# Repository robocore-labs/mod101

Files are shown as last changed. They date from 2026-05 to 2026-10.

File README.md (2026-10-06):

# mod101



**An open-source, universal robot arm platform.**

Robot arms are cool,  but no two people want the same one. Bolt a dremel to it
for light machining and you need a short reach and real payload. Put a camera
on it for inspection work and you want the exact opposite: long reach, almost
nothing to carry. Yet nearly every platform out there, commercial and open
source alike, picks one point on that tradeoff and casts it in stone.

mod101 doesn't. It's a 5-DOF arm designed as a *base* you build on: size it for
your reach envelope, snap in whichever tool the job needs (gripper, vacuum,
camera, dispenser…), and drive it with whatever stack you like — ROS 2, MoveIt,
direct serial, LeRobot.

## Features

- 🔧 **Resize it** — shoulder and elbow extrusions are parametric; tweak from the web configurator with live preview.
- 🧰 **Hot-swap tools** — every end-effector is its own ROS 2 package. Ships with a parallel-jaw gripper, a PincOpen pincer, and a blank end-cap.
- 🤖 **Embeddable** — the whole arm is a prefix-parameterized xacro macro; mount one (or two, or four) on any robot with a one-line `<xacro:mod101_arm .../>` call. No name collisions, no forking.
- 💪 **Lifts up to 3kg and more** with two ST3120 servos — same brackets, just bigger shoulder servos.
- 📏 **Reaches up to 80cm and more** with long extrusions and beefy servos.
- 🌐 **Web configurator** — `python3 configurator/server.py` and you're can use the interactive configurator to tweak the arm to your liking. 
- 🎯 **Guided calibration** — move each joint by hand and the browser learns its limits, flags a binding joint, and writes the config for both ROS 2 and LeRobot.
- 🧠 **MoveIt 2 ready** — motion planning, collision-aware IK and trajectory execution in one launch, with a solver that actually suits a 5-DOF arm. The SRDF is parametric too, so it follows your build.
- 🛠️ **Real structure, not a printed shell** — 2020 aluminum extrusions + PETG-CF brackets at the joints.
- 🌍 **Open** — MIT licensed, no proprietary parts, BOM under $135 entry-level.

## Configurator

**Work out what arm you actually need — before you cut any aluminum or buy a
single servo.**

```bash
source /opt/ros/jazzy/setup.bash   # the 3D preview needs this
python3 configurator/server.py     # then open http://localhost:8001/
```

Drag the sliders and the arm rebuilds itself in front of you. Make the forearm
longer and watch the reach grow — and the payload drop. Swap the shoulder to a
beefier servo and watch it climb back. Every change answers the question that
actually matters when you're about to spend money: *will this arm do my job?*

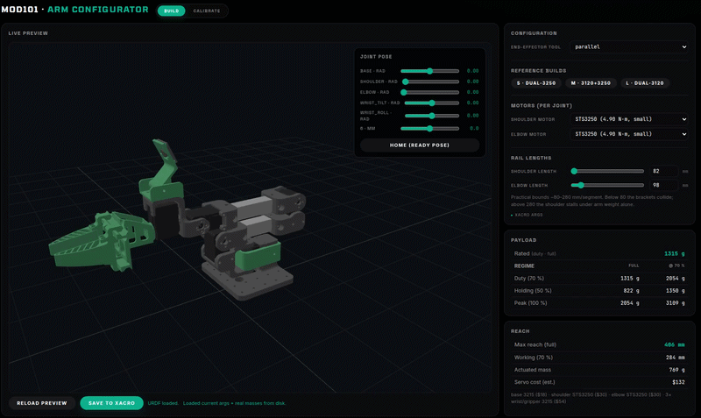
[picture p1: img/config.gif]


Four things to decide:

- **How long** — shoulder and forearm rail lengths, i.e. how far it reaches.
- **How strong** — which servo at the shoulder and the elbow.
- **What's on the end** — gripper, pincer, single jaw, or nothing.
- **Or just start from a preset** — **S**, **M** and **L** are known-good
  builds if you'd rather not start from scratch.

And it tells you, live, what you'd get:

- **What it can lift**, at full stretch and pulled in — plus *which joint*
  gives out first, so you know what to upgrade.
- **How far it reaches** and **what it weighs**, from the real printed part
  masses.
- **What the servos cost** — usually the number that decides the build.

Grab the joint sliders to pose it and check the arm actually reaches into your
workspace. When it looks right, hit **Save**: that configuration *is* your
robot from then on, in sim and on the bench. Nothing to copy by hand.

Endpoint reference and internals: [`docs/configurator.md`](docs/configurator.md).

## Calibration

**You've built the arm. Now teach it where its joints actually stop.**

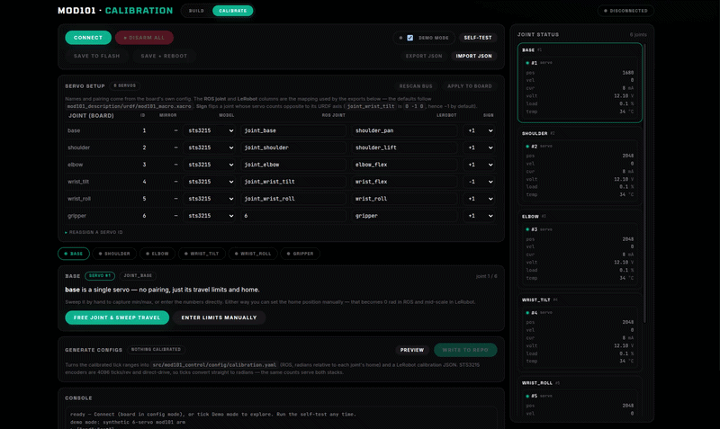
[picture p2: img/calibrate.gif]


Straight off the bench a servo has no idea which way it's mounted or how far
the bracket lets it swing. Calibration is what turns six motors into a robot
that matches the URDF — and it's the step where you find out whether you
assembled it correctly.

Plug the arm and go joint by joint. Each one:

- **Goes limp so you can move it by hand.** Swing it stop to stop and the
  wizard watches where it actually travels — no guessing at limits, no
  numbers to look up. It backs off slightly from each hard stop so the servo
  never grinds.
- **Gets a verdict — clean, binding, or fault.** This is the part worth having.
  A joint that catches, or an encoder that slipped during assembly, shows up
  here as a bad sweep instead of as a crash later with a gripper full of your
  workpiece.
- **Powers up carefully.** It re-arms slowly and checks how hard the servo is
  pulling before letting it move. Too much current and it disarms itself,
  which usually means something is fighting the joint.
- **Gets a drive test**, so you can watch it track across the range you just
  set before trusting it.

The arm is left powered down at every exit, including if you close the tab or
yank the cable.

When you're done, **Write to repo** saves the results for both ROS 2 and
LeRobot, so the arm you calibrated is the arm your code drives.

No hardware yet? Tick **Demo mode** and the whole flow runs against a
simulated arm — a good way to see what you're in for before you order servos.

Talks to the servos directly over the USB-TTL adapter (`pip install st3215`) —
no intermediate firmware, and nothing is written to servo EEPROM. Any browser.
Full details, including the joint/servo mapping and the tick math:
[`docs/calibration.md`](docs/calibration.md).

## Tools

Every end-effector is a standalone ROS 2 package (`mod101_tool_<name>`) carrying its own URDF, controllers, gazebo extensions, and launch fragment. Pick one at launch time with `tool:=<name>`.

| Tool | Preview | Description | 
|---|---|---|
| `parallel` |  | Parallel-jaw gripper, single prismatic joint with a mimic'd right jaw. |
| `pincopen` |  | [PincOpen](https://github.com/CNURobotics/pinc_open_driver) pincer gripper (Pollen Robotics). Single revolute drive + 4-bar linkage. | 
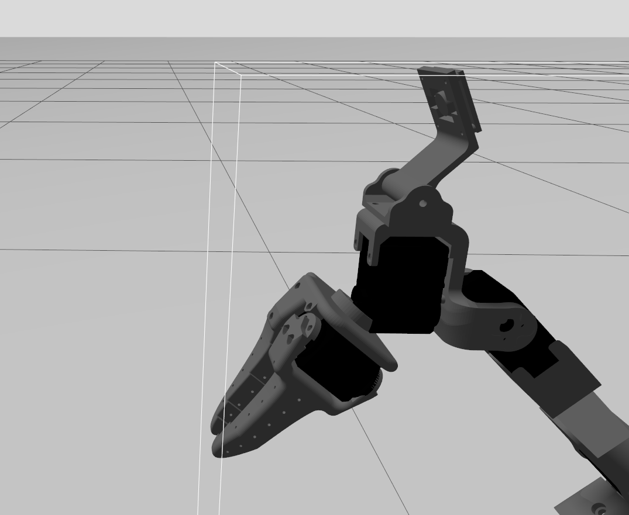
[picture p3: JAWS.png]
| `jaws` |  | SO-101 single-jaw gripper — moving jaw rotates against the fixed wrist-roll body. Cheapest tool, just one extra servo. **Default.** | 
| `none` |  | Blank end-cap. No actuators — useful as a baseline or a template for a new tool. |

Adding your own is a one-package job (URDF + ros2_control + SRDF + launch). See [`docs/tool-convention.md`](docs/tool-convention.md) for the coordinate convention every tool follows, and [`docs/ros-architecture.md`](docs/ros-architecture.md#adding-a-new-tool) for the package contract.

## Getting started

You'll need ROS 2 Jazzy on Ubuntu 24.04. Everything else (Gazebo Harmonic, `ros2_control`, `gz_ros2_control`) installs via apt.

```bash
# 1. Clone next to (or into) a colcon workspace
git clone https://github.com/<you>/mod101.git ~/robots/mod101
cd ~/robots/mod101

# 2. Build the arm + the tools you want
colcon build --packages-select \
  mod101_description mod101_control mod101_gazebo mod101_moveit_config \
  mod101_tool_parallel mod101_tool_pincopen mod101_tool_jaws mod101_tool_none
source install/setup.bash

# 3. Launch sim — pick a tool with the `tool:=` arg
ros2 launch mod101_gazebo gazebo.launch.py tool:=parallel
```

### Or in containers

Two containers, no ROS install needed: the simulation (this repo, built into
one image) and the robocore agent (pulled, not built here).

```bash
docker compose -f docker/compose.yaml up --build
```

That gives you the bench in Gazebo plus the robocore API on
`ws://localhost:10101`. The agent needs no configuration beyond
`profiles/mod101_harness.yaml`, which compose mounts for you.

Want motion planning? `sudo apt install ros-jazzy-moveit ros-jazzy-pick-ik`, then:

```bash
ros2 launch mod101_moveit_config demo.launch.py   # Gazebo + MoveIt + RViz
```

Plan and execute from the RViz MotionPlanning panel. Full walkthrough, including
a scripted first motion:
[`docs/moveit-getting-started.md`](docs/moveit-getting-started.md).

One thing worth knowing up front: mod101 is a 5-DOF arm, so it plans to
**positions**, not full 6-DOF poses — the guide explains why and what that means
for grasps.

Try the configurator while sim is running:

```bash
python3 configurator/server.py  # http://localhost:8001/
```

## Running on real hardware

The bench in containers, against the actual arm. Same shape as the sim stack:
one image built from this repo, one pulled for the agent.

**Calibrate first.** The arm has no configuration stored on it, so without a
calibration every joint angle is offset by wherever its servo horn happened to
be splined on. See [`docs/calibration.md`](docs/calibration.md); it takes a few
minutes per joint and only has to be done once per arm.

```bash
docker compose -f docker/hardware.compose.yaml up --build
```

That is the whole thing. The build clones the driver packages itself
(`src/hardware/hardware.repos`), and the servo bus is found at
`/dev/mod101-servo`. `docker/hardware.env.example` covers the cases that differ
from this bench; none of it is required.

**Install the udev rules once**, so the bus and the camera come up under names
that survive a replug:

```bash
sudo cp docker/udev/*.rules /etc/udev/rules.d/
sudo udevadm control --reload-rules && sudo udevadm trigger
ls -l /dev/mod101-servo          # -> ../ttyACMn
```

The servo rule matches the RS-485 adapter by **serial number**, so edit it if
you swap cables (the file says how). Without it, set `MOD101_BUS=/dev/ttyACMn`
in `.env` and re-check it after every replug. The RealSense rule grants raw USB
access to a non-root container; **replug the camera** after installing it,
because udev does not re-apply modes to a device that is already open.

Working on the drivers? The image contains what is on `main`, not what is
checked out locally — push first, then bust the cached clone:

```bash
docker compose -f docker/hardware.compose.yaml build \
  --build-arg DRIVERS_CACHEBUST=$(date +%s)
```

That gives you three things:

| | |
|---|---|
| the robot | `ros2_control` on the real servo bus, plus per-motor telemetry on `/motor_telemetry/<joint>/*` |
| the head camera | the D435 on `/harness/depth_camera/*` — the same topic names the sim publishes |
| <http://localhost:8888> | ROSBoard — the graph in a browser, **and joint sliders that move the arm** |
| `ws://localhost:10101` | the robocore agent |

Stop it with `docker compose -f docker/hardware.compose.yaml down`. Use that
rather than Ctrl-C'ing a host launch: killing a launch by hand takes the
launcher and leaves its `robot_state_publisher` running, which then publishes
`/robot_description` and TF into the *next* run's graph.

### Before the first run

**Bringing the stack up energises the arm.** Every servo is armed and told to
hold its present position — no jump, but live and drawing current. Two things
follow from that:

- **Put the arm somewhere it can hold, and near its calibrated home.** A joint
  resting outside its calibrated travel gets its first command clamped back
  into range, which turns "hold still" into a move of however far outside it
  was. The driver refuses to start when that distance is more than a few
  degrees, rather than making the move.
- **There is no e-stop in this stack.** `brake_method: torque_disable` drops
  torque when a group is commanded to stop; nothing here cuts power.

A dry run first is free, and touches nothing:

```bash
docker compose -f docker/hardware.compose.yaml run --rm --no-deps hardware \
  ros2 launch mod101_hw_bringup bringup.launch.py \
  hardware:=mock bus:=false cameras:=false
```

`bus:=false` is the real dry run — the servo driver does not start, so nothing
is energised. `hardware:=mock` alone is not: it only swaps the `ros2_control`
plugin, and the driver is a separate node that arms motors regardless.

### When it doesn't come up

| what it says | what it is |
|---|---|
| `N of M motors did not answer` | motor power. The logic side is USB-fed, so the port opens and the chain stays silent — it looks like a working driver with a dead robot |
| `is at N, outside its calibrated travel` | move that joint back by hand (torque is off) and start again, or recalibrate if the range is wrong |
| `could not open port` | no `/dev/mod101-servo` (udev rules not installed?), or the container user is not in the host's `dialout` group (`DIALOUT_GID` in `.env`) |
| `NO CALIBRATION at ...` | it will run, uncalibrated, and every angle will be wrong. Run the configurator |
| camera: `no device detected` while `lsusb` shows it | the RealSense udev rule is missing or the camera was not replugged after installing it. The `cameras` service runs as your UID and librealsense needs raw USB **write** access |

Prefer `/dev/mod101-servo` to `/dev/ttyACMn`. ACM numbering is assignment
order, not identity, and it moves whenever anything re-enumerates — it shifted
once mid-session on this bench. Getting it wrong does not report a wrong port:
the port opens, nothing answers, and it reads as unpowered motors.

The cameras are their own service, so they can be restarted, stopped or
followed without touching the arm:

```bash
docker compose -f docker/hardware.compose.yaml logs -f cameras
docker compose -f docker/hardware.compose.yaml restart cameras
```

Full detail, including the arguments and what each config file owns:
[`src/hardware/mod101_hw_bringup/README.md`](src/hardware/mod101_hw_bringup/README.md).

## Embedding in another robot

The arm is defined as the `mod101_arm` xacro macro
(`mod101_description/urdf/mod101_macro.xacro`); the standalone `mod101.xacro`
is just a thin wrapper that instantiates it once with an empty prefix. Any
robot can include the macro file and bolt on as many arms as it likes:

```xml
<xacro:include filename="$(find mod101_description)/urdf/mod101_macro.xacro"/>

<xacro:mod101_arm prefix="left_arm_"  parent="left_arm_bracket"
                  xyz="0 0.06 0.024" rpy="0 0 0"
                  tool="jaws" use_sim="true"/>
<xacro:mod101_arm prefix="right_arm_" parent="right_arm_bracket"
                  xyz="0 -0.06 0.024" rpy="0 0 0"
                  tool="jaws" use_sim="true"/>
```

| Param | Default | Meaning |
|---|---|---|
| `prefix` | `''` | Prepended to **every** link/joint name. Joints become e.g. `left_arm_1 … left_arm_6`; the wrist camera topic becomes `<prefix>wrist_camera/image_raw`. |
| `parent` | `''` | Link to bolt the arm base onto via a fixed `<prefix>base_mount` joint. Empty = no mount joint (the caller anchors `<prefix>base_link` itself). |
| `xyz`, `rpy` | `0 0 0` | Mount joint origin in the parent frame. The base plate is 80×100 mm, centred on `base_link`. |
| `tool` | `jaws` | End-effector package (`mod101_tool_<tool>`). |
| `use_sim` | `true` | Emit the gz_ros2_control hardware blocks + gazebo extensions. |

The macro emits a complete, independently named `<ros2_control>` system per
instance (plus one per tool), so a single `gz_ros2_control` plugin /
controller_manager handles them all — the integrator just declares the
plugin once and supplies controller YAML with the prefixed joint names. The
reference integration is the base101 dual-arm workspace (two arms on a
mobile base's lift tower).

## Optional: `mod101_harness`

`mod101_harness` is an **optional overlay** package (built with the rest,
depended on by nothing): the arm on a bench test harness — 2020 extrusion base,
camera tower with an actuated pan/tilt head and a RealSense depth camera. It
reuses mod101's arm description and controller set unchanged and adds only the
harness structure, the two `hn_pan_joint` / `hn_tilt_joint` joints (one extra
controller, `config/pan_tilt_controllers.yaml`) and the depth camera. Two
launch files:

```bash
# whole robot in Gazebo: arm + pan/tilt + RealSense depth (RGB/depth/points on
# /harness/depth_camera/*) + the arm's wrist camera, all bridged
ros2 launch mod101_harness sim.launch.py

# prepared-for-hardware skeleton: robot_state_publisher + controller_manager on
# a mock_components placeholder, same controllers spawned. Runs as fake hardware
# as-is; swap the plugin in urdf/mod101_harness_arm.xacro to go live.
ros2 launch mod101_harness hardware.launch.py
```

Same `tool:=` / rail-length / mount args as `mod101_gazebo`. No MoveIt launch —
point `mod101_moveit_config`'s `move_group` at this package's xacro/srdf if you
want planning. The arm mount pose was solved by rigidly aligning the export's
stand-in base against `base_link.stl`; `urdf/harness_body.xacro` is the ported
geometry, `export/` the untouched baseline for the next re-export.

### Deeper docs

**Get it moving**

- **[docs/moveit-getting-started.md](docs/moveit-getting-started.md)** — the walkthrough: install to first executed motion, ~15 minutes, no hardware
- **[docs/moveit.md](docs/moveit.md)** — the MoveIt reference: the 5-DOF IK story, what to regenerate when you change the build, controller wiring, and what every planning failure means

**Change it**

- **[docs/configurator.md](docs/configurator.md)** — sizing the arm: endpoint reference, how the live xacro edit works, what a Save does and doesn't do
- **[docs/tool-convention.md](docs/tool-convention.md)** — coordinate convention for tool URDFs (mount joint identity, `+X` outward, `+Z` up, bolt pattern at origin)
- **[docs/calibration.md](docs/calibration.md)** — hardware bring-up: the per-joint sweep wizard, and the ROS + LeRobot config it generates

**Understand it**

- **[docs/ros-architecture.md](docs/ros-architecture.md)** — package layout, the tool contract, controllers, the joint table, real-hardware wiring, known gotchas
- **[docs/performance-notes.md](docs/performance-notes.md)** — measured performance, where bringup time really goes, and the middleware traps that masquerade as code bugs

**History** — kept for reasoning and measurements, not current documentation

- **[docs/worklogs/moveit.md](docs/worklogs/moveit.md)** — the original MoveIt handover note and the collision-matrix measurements behind today's design

## BOM

### Base Config (~$134)

| Part | Qty | Unit Price | Subtotal |
|---|---|---|---|
| [STS3215 servo (12V, 30 kg·cm)](https://www.alibaba.com/product-detail/Low-Cost-Feetech-STS3215-Servo-7_1601611431055.html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) | 6 | $16.50 | $99.00 |
| 2020 aluminum extrusion (cut to length) | ~0.6m | $5.00/m | $3.00 |
| M5 T-nuts | ~20 | — | $3.00 |
| M5×8 bolts | ~20 | — | $2.00 |
| PLA-CF filament (~150g) | — | — | $8.00 |

| Misc hardware (bolts, nuts, wires) | — | — | $10.00 |
| **Total** | | | **~$134** |

If you want to upgrade the motors for more payload, here are the options: [**STS3250 at 50kg*cm**](https://www.alibaba.com/product-detail/12V-50kg-STS3250-Coreless-Motor-Magnetic_1601756525163.html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) or [**the 120kg*cm beast STS3120**](https://www.alibaba.com/product-detail/Feetech-STS3120M-12V-120kg-High-Performance_1601816393864.html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). Brackets are available for both, check the configurator for more details. 

## Related Projects

- **[Axon](https://github.com/robocore-labs/link101-hw)** — RP2350-based multi-protocol bridge (CAN FD / RS485 / Dynamixel / Feetech)
- **[Forge](https://github.com/cristidragomir97/forge)** — ROS 2 deployment orchestration

## Acknowledgments

- Derived from the [SO-101](https://github.com/TheRobotStudio/SO-ARM100) by The Robot Studio.
- Parallel-jaw gripper is the [PathOn 6DOF symmetric gripper](https://github.com/PathOn-AI/pathon_opensource).
- PincOpen pincer tool vendors URDF + meshes from [CNURobotics/pinc_open_driver](https://github.com/CNURobotics/pinc_open_driver) (original gripper design by Pollen Robotics).

## License
MIT

## 6DOF / 7DOF arm variants

Choose **Arm variant** in the configurator. The selector updates the preview,
servo cost and payload estimate; **Save to xacro** persists it for ROS launches.
Both variants use the same end-effector packages and `wrist_flange` interface.
The project's names count the tool actuator: 6DOF has five arm axes; 7DOF adds
`joint_wrist_yaw` before wrist pitch/roll, giving six arm axes. With `tool:=none`
there is no tool actuator.

```bash
source /opt/ros/jazzy/setup.bash
colcon build --symlink-install
source install/setup.bash
ros2 launch mod101_moveit_config mock.launch.py arm_dof:=7 tool:=pincopen
# Other description, Gazebo, harness and hardware launches accept arm_dof too.
```

For an imported arm, pass `arm_dof="7"` to `mod101_arm` and the matching
`mod101_arm_srdf`. The default remains 6, preserving existing consumers.
Include `mod101_config.xacro` and pass `arm_dof="$(arg arm_dof)"` to follow the
saved configuration. Each instance can select its own variant and tool.

The added wrist geometry and shaft pivots come from `mod101_7DOF.step`; the STEP
has 100 mm shoulder and 110 mm elbow rails. Rail lengths remain configurable.
The added yaw servo is an STS3215, **56 g**, with provisional **±90°** limits.
Default bus ID is **9**, preserving tool ID 6 and head IDs 7/8. Calibrate the new
joint and write a matching servo map before hardware use; an old map with the
wrong joint set is rejected by hardware bring-up.

Payload estimates preserve the existing 6DOF/jaws reference calculation,
including its joint-capacity and lumped-weight assumptions. The user confirmed
the 140/140 mm jaws configuration lifts over 700 g on the bench; its previous
calculator result remains unchanged (911 g duty/full with STS3250 selections).
The 7DOF model applies differences calculated from both URDFs at identical rail
lengths: the new actuator/printed masses, COMs and changed load-point leverage.
Other tools use the same correction relative to jaws. This extrapolation needs
its own bench validation; it does not establish a rated load. Existing estimated arm plastics and the new wrist use **PETG,
1.27 g/cm³, 15% infill, 1.6 mm shell**. The separate tool packages retain their
own authored mass estimates. New wrist mass/inertia provenance is recorded in
`src/mod101_description/config/7dof_measurements.json`; print COM/inertia uses
uniform effective density. Slicer or measured weights can improve these estimates.

The calculator evaluates a horizontal extended pose. Tool reach uses its distal
visual extent as a provisional load point; 70% reach scales the levers rather
than solving a new pose. Stall-torque fractions are estimates, not rated payloads.
After saving lengths/mounts, rebuild collision matrices from the configurator;
its regeneration samples both arm variants independently for every tool.

```bash
python3 -m pytest tests/test_arm_variants.py
python3 src/mod101_moveit_config/test/moveit_smoke.py --arm-dof 7
# The second command needs the matching mock launch running.
```

The configurator's **Wrist camera** checkbox controls the camera, both printed
mounts, sensor/frame definitions and MoveIt collision references on either arm
variant. **Save to xacro** persists it. ROS launches also accept
`wrist_camera:=false`; imported URDF and SRDF macros accept `wrist_camera="false"`.
Hardware bring-up skips the wrist-camera driver when the option is disabled.

The parallel tool now includes a black STS3215 servo visual in its existing
body link. The mesh is reused from the repository's CAD extraction; the tool's
existing combined body mass/inertia remains unchanged.

## Camera mount tool and package-defined options

Select **Camera mount** in the configurator to choose between **Luxonis (61 g)**
and **RealSense (72 g)**, with an optional **GoPro (153 g)** above it. The PETG
holder is approximately **46.2 g** at 15% infill with the 1.6 mm shell assumption.
Both 6DOF and 7DOF variants support the same options and include their mass in
the payload estimate. The existing jaws reference calculation is preserved.

`mod101_tool_camera` includes the STEP-derived meshes, authored inertials and
`camera_tool_gopro_optical_frame`. It is passive and requires no tool actuator.
See [camera package notes](src/mod101_tool_camera/README.md) and the
[tool options API](docs/tool-options.md) for the YAML schema and ROS arguments.

### NormaCore PGGripper

Select **PGGripper** in the configurator or pass `tool:=pggripper` to the existing launch commands. The [end-effector package](src/mod101_tool_pggripper/README.md) includes its ST3215 servo, rack-and-pinion jaw motion, ROS controllers and collision matrices for both arm variants. Estimated mass is 154g using PETG at 15% infill; rated aperture is 54mm.

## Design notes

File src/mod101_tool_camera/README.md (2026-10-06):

# Camera mount end effector

Passive wrist-flange tool extracted from `camera_tool.step`. The mount origin
is the rear face at the centre of the +/-7 mm bolt pattern. +X points out of
the lenses; +Z places the GoPro above the selected depth camera.

In the configurator select **Camera mount**, choose **Luxonis** or **RealSense**,
and optionally enable **Top GoPro**. Save to persist the configuration.
The primary cameras are mutually exclusive in the URDF, not merely hidden
in the preview. The GoPro body, mass, and optical frame are all removed when off.

```bash
ros2 launch mod101_moveit_config mock.launch.py \
  tool:=camera camera_sensor:=realsense camera_gopro:=true arm_dof:=7
```

Imported `mod101_arm` macros accept `camera_sensor` and `camera_gopro` per
instance. The paired `mod101_arm_srdf` accepts the same GoPro flag. No extra
joint, controller, or servo is created; camera drivers are separate from this
mechanical description package.

| Component | Mass |
|---|---:|
| PETG holder (15% infill, 1.6 mm shell, 1.27 g/cm³) | 46.2 g estimated |
| Luxonis | 61 g (user supplied) |
| RealSense | 72 g (user supplied) |
| GoPro | 153 g (user supplied) |

The holder includes its GoPro mounting fork even with the camera absent.
COM/inertia assume uniform effective density in each CAD component; camera
masses use the supplied weights. Source hash, geometry measurements, tensors,
and the CAD-to-tool transform are recorded in `config/measurements.json`.
`tools/export_camera_tool.py` reproduces the meshes and mass measurements;
`urdf/tool.urdf.xacro` remains the authored robot description.

`<prefix>camera_tool_gopro_optical_frame` follows REP-103: +Z forward, +X image
right, +Y down. Its origin is the front lens-window centre measured from CAD,
at `(35.1851, 21.5930, 66)` mm in tool coordinates. It is a mechanical reference;
use camera calibration for imaging intrinsics and precise optical extrinsics.
The GoPro stays fixed at its exported pose.

Visual meshes preserve the vendor STEP surfaces, including imported seams;
collision shapes are conservative boxes. The primary box is the union of both
camera envelopes so the sampled collision matrix is valid for either choice.
Collision pairs involving the optional GoPro are omitted when it is disabled.

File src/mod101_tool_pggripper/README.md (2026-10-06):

# PGGripper for mod101

Adapted from [NormaCore Parallel Jaw Gripper](https://github.com/norma-core/norma-core/tree/main/hardware/pgripper), licensed Apache-2.0. Original license and STEP are included. Meshes and kinematic description are adapted for mod101; upstream optional webcam/mount are omitted. Keep mod101 wrist camera enabled if required.

Select **PGGripper** in the configurator, or pass `tool:=pggripper` to the normal ROS launch commands. Supports both 6DOF and 7DOF, prefixed multi-arm macros, gripper position and trajectory controllers.

Joint `6` is the motor rotation in radians, zero closed and approximately 2.271 radians fully open. Two passive prismatic mimic joints convert rotation through the CAD rack pitch (4.15mm, 18 teeth); 27mm travel per jaw / 54mm aperture. Imported STEP is at a measured 50mm aperture. Servo mounting orientation and phase are retained; calibrate motor zero/sign on hardware before commanding it.

Mass estimate: PETG 15% infill with 1.6mm shell, 56g ST3215-family actuator, steel hardware at 7850kg/m³. Total approximately 154g, with CAD-derived COM and inertia. These are estimates, not weighed parts; upstream filament requirement includes print supports and differs. Cameras are not included in this package mass.

`config/measurements.json` records datums, source hash and computed mass properties. `tools/export_pggripper.py` exports meshes/measurements; authored xacro owns the robot description. Imported CAD includes faces without mesh triangulation; collision checking uses the available triangulated geometry.

The hardware interface follows the existing gripper bridge/mock/Gazebo selection. Motor torque and speed limits are provisional (1.9Nm, 2rad/s). Passive sliders have no command interfaces.

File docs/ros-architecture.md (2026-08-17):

# ROS 2 architecture

mod101 follows the standard ROS 2 description / control / gazebo layout, with a **modular tool layer**: every end-effector lives in its own `mod101_tool_<name>` package that ships everything it needs (URDF, ros2_control hardware block, gazebo extensions, controllers YAML, launch).

Target distro: **Jazzy** (Ubuntu 24.04, Python 3.12, Gazebo Harmonic).

## Packages

| Package | Build type | Purpose |
|---|---|---|
| `mod101_description` | `ament_cmake` | Arm URDF/xacro, meshes, RViz config, `display.launch.py`. The arm itself is the **`mod101_arm` macro** in `mod101_macro.xacro` (prefix-parameterized so multiple instances can coexist in one robot); `mod101.xacro` is the thin standalone wrapper; `mod101.ros2control` / `mod101.gazebo` hold the matching per-instance macros. Terminates at the `wrist_flange` link — the contract point for tools. |
| `mod101_control` | `ament_cmake` | Arm controller YAML (`controllers.sim.yaml`), real-hardware overlay (`mod101.hardware.xacro` — placeholder plugin) |
| `mod101_gazebo` | `ament_cmake` | World (`empty.sdf`, bullet-featherstone physics), bridge config, `gazebo.launch.py` (accepts `tool:=<name>`) |
| `mod101_tool_parallel` | `ament_cmake` | Parallel-jaw gripper |
| `mod101_tool_pincopen` | `ament_cmake` | PincOpen pincer gripper (vendored from [CNURobotics/pinc_open_driver](https://github.com/CNURobotics/pinc_open_driver)) |
| `mod101_tool_jaws` | `ament_cmake` | SO-101 single-jaw gripper (URDF + meshes adapted from the SO-101 lineage) |
| `mod101_tool_none` | `ament_cmake` | Empty end-cap. No actuators, no controllers — useful as a baseline / template |
| `mod101_moveit_config` | `ament_cmake` | MoveIt 2: parametric SRDF (`srdf/mod101.srdf.xacro`), 5-DOF-aware IK, generated collision matrices, `demo`/`mock`/`move_group` launches. See [moveit.md](moveit.md) |

## The `mod101_arm` macro

Everything that *is* the arm — links, joints, ros2_control hardware block,
gazebo extensions, the selected tool — is emitted by one macro:

```xml
<xacro:include filename="$(find mod101_description)/urdf/mod101_macro.xacro"/>
<xacro:mod101_arm prefix="" parent="world" xyz="0 0 0" rpy="0 0 0"
                  tool="jaws" use_sim="true"/>
```

`prefix` is prepended to every link/joint/system name and the wrist-camera
topic, so multiple instances coexist cleanly (`left_arm_1…6`, etc.).
`parent` adds a fixed `<prefix>base_mount` joint to the given link (empty =
no mount joint). `use_sim` gates the gz_ros2_control system blocks + gazebo
tags per instance.

Two things deliberately stay **outside** the macro, in the standalone
wrapper `mod101.xacro`: the `world` anchor link and the gz_ros2_control
**plugin** declaration (one per robot — an integrator with its own plugin
block, like base101, must not inherit a second one). `mod101.xacro` keeps
the original `use_sim` / `tool` args, so single-arm bringup is unchanged.

## Tool layer

The macro's `tool` param (arg `tool` on the standalone wrapper, default
`jaws`) selects which `mod101_tool_<tool>` macro to invoke; the tool's links
are fixed-jointed to `<prefix>wrist_flange`. The Gazebo plugin block in
`mod101.xacro` loads `mod101_control`'s arm YAML **plus** the active tool's
YAML (multiple `<parameters>` files merge into the single
`controller_manager` namespace); the launch file `IncludeLaunchDescription`s
the tool's `launch/tool.launch.py` to spawn whatever controllers / bridges /
drivers the tool needs.

### Adding a new tool

Create `mod101_tool_<name>/` with:

```
urdf/tool.urdf.xacro        # macro mod101_tool_<name>(prefix, use_sim): links + fixed joint to ${prefix}wrist_flange
urdf/tool.ros2control       # optional: macro mod101_tool_<name>_ros2control(prefix, use_sim)
urdf/tool.gazebo            # optional: macro mod101_tool_<name>_gazebo(prefix)
srdf/tool.srdf.xacro        # optional: macro mod101_tool_<name>_srdf(prefix) — MoveIt group + end effector
config/controllers.yaml     # optional
config/moveit_controllers.yaml  # optional: this tool's FollowJointTrajectory entry for MoveIt
launch/tool.launch.py       # spawners, image bridges, drivers, ...
```

`launch/tool.launch.py` must declare a `spawn_controllers` argument (even if it
ignores it, as `mod101_tool_none` does) — `mod101_gazebo` passes it to every
tool launch, and an include handed an argument it doesn't declare is an error.

Every link/joint name and parent/child reference inside the macros takes a
`${prefix}` (copy an existing tool — `jaws` is the smallest complete
example). Then add one include + one `<xacro:if>` invocation branch in
`mod101_macro.xacro`, one `<parameters>` branch in `mod101.xacro`'s
plugin block (if the tool ships controllers), and — if it ships SRDF semantics —
one include + branch in `mod101_moveit_config/srdf/mod101.srdf.xacro`, then run
`python3 tools/gen_collision_matrix.py --tool <name>`. The configurator
auto-discovers the package on disk and lists it in the dropdown.

## Joints

Arm, base outward — 5 DOF, all `<prefix>`-prefixed:

| Joint | Type | Axis | Limits |
|---|---|---|---|
| `joint_base` | revolute | +Z (yaw) | ±1.5708 |
| `joint_shoulder` | revolute | +Y (pitch) | −0.001 … 3.1416 |
| `joint_elbow` | revolute | −Y (pitch) | −0.001 … 3.1416 |
| `joint_wrist_tilt` | revolute | −Y (pitch) | −1.23 … 1.54 |
| `joint_wrist_roll` | revolute | +X (roll) | 0 … 3.1416 |

Two details in that table are load-bearing, not typos:

- **The wrists are `revolute`, not `continuous`.** They were `continuous` (no
  `lower`/`upper`) until measured travel landed. Unbounded joints inside the
  `arm` group give `pick_ik` no interval to sample, so it rejects its own seed
  with *"Initial guess exceeds joint limits"* and every goal fails.
- **The shoulder and elbow stops are at `−0.001`, not `0.0`.** The hard stop is
  at zero, but Gazebo settles the joint a picoradian below it and MoveIt's
  `CheckStartStateBounds` adapter then rejects the start state and aborts the
  pipeline before OMPL runs. 1 mrad of margin is mechanically negligible and far
  above the noise. Real encoders behave the same way.

One yaw, three *parallel* pitches, one roll. That spans position plus tool
pitch, but the tool's azimuth is rigidly tied to `joint_base` — the arm cannot
reach an arbitrary 6-DOF pose, which is why MoveIt uses a position-only IK
solver (see [moveit.md](moveit.md)).

`effort="100" velocity="100"` on every joint is placeholder data from the CAD
export, not servo spec — real dynamics limits live in
`mod101_moveit_config/config/joint_limits.yaml`.

- Tool joints live in the tool package, and the drive joint is always named `<prefix>6`. For `mod101_tool_parallel`: `<prefix>6` (prismatic, drives `left_jaw`); `<prefix>right_jaw_slider` follows via URDF `<mimic>` (bullet-featherstone honors it; dartsim doesn't).

## Build

```bash
cd ~/robots/mod101
colcon build --packages-select \
  mod101_description mod101_control mod101_gazebo mod101_moveit_config \
  mod101_tool_parallel mod101_tool_pincopen mod101_tool_jaws mod101_tool_none
source install/setup.bash
```

## Run

RViz only (no physics, joint sliders):

```bash
ros2 launch mod101_description display.launch.py
```

Gazebo sim with ros2_control:

```bash
ros2 launch mod101_gazebo gazebo.launch.py                 # tool:=jaws (default)
ros2 launch mod101_gazebo gazebo.launch.py tool:=parallel
ros2 launch mod101_gazebo gazebo.launch.py tool:=pincopen
ros2 launch mod101_gazebo gazebo.launch.py tool:=none
```

With MoveIt (planning + execution; walkthrough in [moveit-getting-started.md](moveit-getting-started.md), reference in [moveit.md](moveit.md)):

```bash
ros2 launch mod101_moveit_config demo.launch.py               # Gazebo + move_group + RViz
ros2 launch mod101_moveit_config mock.launch.py               # no Gazebo, mock hardware
```

## Controllers

Controllers active after launch (with `tool:=parallel`):

| Controller | Type | Joints | Owner | State at boot |
|---|---|---|---|---|
| `joint_state_broadcaster` | broadcaster | — | `mod101_gazebo` | active |
| `arm_controller` | `position_controllers/JointGroupPositionController` | arm 5 | `mod101_gazebo` | **active** (default) |
| `gripper_controller` | `position_controllers/JointGroupPositionController` | 6 | `mod101_tool_parallel` | active |
| `arm_trajectory_controller` | `joint_trajectory_controller/JointTrajectoryController` (JTC) | arm 5 | YAML in `mod101_control` | defined, **not spawned** here — MoveIt spawns it, see note below |
| `gripper_trajectory_controller` | JTC | 6 | `mod101_tool_<tool>` | defined, **not spawned** here — MoveIt spawns it |

Send a position command:

```bash
ros2 topic pub /arm_controller/commands std_msgs/msg/Float64MultiArray "{data: [0.0, 0.5, -0.5, 0.0, 0.0]}"
ros2 topic pub /gripper_controller/commands std_msgs/msg/Float64MultiArray "{data: [0.013]}"
```

### JTC is not spawned by the *plain* gazebo launch

Not because it's broken — because `arm_trajectory_controller` and
`arm_controller` claim the same five joints, and `controller_manager` allows
only one active claim per joint. The plain sim gives you the simple
Float64MultiArray interface; MoveIt needs the trajectory one.

Don't spawn-then-switch. Pass `spawn_controllers:=false` to
`gazebo.launch.py` (it also forwards to the active tool's launch, suppressing
`gripper_controller`) and spawn the trajectory controllers instead — which is
exactly what `mod101_moveit_config/launch/demo.launch.py` does:

```bash
ros2 launch mod101_moveit_config demo.launch.py
```

**Historical note:** JTC used to segfault in `on_init()` under `gz_ros2_control`
([ros2_control issue #2400](https://github.com/ros-controls/ros2_control/issues/2400)).
That is **fixed** as of `ros2_control` 4.45.2 / `gz_ros2_control` 1.2.19 —
JTC loads, activates, and executes `FollowJointTrajectory` goals in Gazebo.
Verified by `mod101_moveit_config/test/moveit_smoke.py`.

## Wiring real hardware

Override `mod101.xacro`'s `use_sim` arg to `false` and switch `mod101.hardware.xacro`'s placeholder `mock_components/GenericSystem` plugin for the real servo bus driver.

Calibrate the physical arm first — the configurator's Calibrate tab sweeps each
joint and generates `mod101_control/config/calibration.yaml` (joint limits in
radians, per-servo tick ranges) plus a LeRobot calibration JSON. See
[calibration.md](calibration.md).

## Gotchas

- `/clock` must have exactly **one** publisher. `gazebo.launch.py` runs a dedicated `clock_bridge`; do not also list `/clock` in `config/gz_ros_bridge.yaml`. Two bridges sample Gazebo independently, sim time appears to run backwards, and every sim-time subscriber spams `Detected jump back in time. Clearing TF buffer.` (this broke MoveIt's TF lookups).
- `update_rate` is **int** (`100`, not `100.0`) — Jazzy crashes on float.
- `state_publish_rate`, `action_monitor_rate` are **double** (`50.0`, `20.0`).
- `controller_manager.catch_exceptions: true` keeps gazebo alive when a controller's `on_init()` throws — real error is in the line just above the C++ stack trace.
- Physics engine is **bullet-featherstone** (set in `worlds/empty.sdf`) so URDF `<mimic>` works (used by `mod101_tool_parallel` for `right_jaw_slider`, and by `mod101_tool_pincopen` for all four 4-bar joints). Switching back to dartsim drops mimicked joints.
- Each `mod101_tool_*` package needs at least one node in its `launch/tool.launch.py` for `IncludeLaunchDescription` to be happy — `mod101_tool_none` ships an empty `LaunchDescription([])` and that's fine.
- `GZ_SIM_RESOURCE_PATH` must include each tool's install prefix so Gazebo can resolve `package://mod101_tool_<name>/meshes/...`. The main `gazebo.launch.py` builds this list automatically from the active tool.

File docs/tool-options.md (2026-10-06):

# Tool options API (version 1)

A `mod101_tool_<name>` package can supply `config/configurator.yaml`. The
configurator discovers these files, renders their controls with the standard
panel styling, validates values, forwards them to xacro, and saves them as
arguments in `mod101_description/urdf/mod101_config.xacro`. ROS description,
Gazebo, mock, MoveIt and hardware launches discover the same arguments from
installed package metadata. The shared implementation is
`mod101_description/tool_config.py`; the frontend has no camera-specific logic.

```yaml
schema_version: 1
label: Camera mount
actuated: false
servo_count: 0
options:
  camera_sensor:
    type: enum
    label: Depth camera
    default: luxonis
    choices:
      - {value: luxonis, label: "Luxonis · 61 g"}
      - {value: realsense, label: "RealSense · 72 g"}
  camera_gopro:
    type: boolean
    label: Top GoPro · 153 g
    default: false
```

Version 1 supports `enum` and `boolean`. Option names must use lowercase letters,
digits and underscores, start with a letter, and be unique across tool packages;
namespace them by tool. Core arguments such as `tool`, `arm_dof` and
`wrist_camera` are reserved. Enum choices define accepted values; arbitrary
strings and non-boolean values are rejected before saving. Omitted values retain
their saved settings or use the schema default. Packages without a manifest keep
the existing UI and derive actuator presence from their controller YAML.

The schema describes controls; it does not generate robot geometry. The tool's
authored xacro declares the corresponding arguments and uses them to select
links, meshes and inertials. `mod101_tool_camera/urdf/tool_config.xacro` reads
its defaults directly from the YAML, avoiding a second default-value source.
Arm wrappers pass the arguments into the tool macro; imported arm instances can
pass their own values independently. A new tool still registers its URDF/SRDF
macro with the arm and provides appropriate collision data.

`GET /tool` returns `schemas` and saved `options`. `GET /load` returns saved
`tool_options`. Live `/urdf` and `/payload` requests accept the declared argument
names as query parameters. `POST /save` accepts `tool_options` as an object:

```json
{"shoulder": 0.14, "elbow": 0.14,
 "tool_options": {"camera_sensor": "realsense", "camera_gopro": true}}
```

Passive tools ship an empty `config/controllers.yaml` and an empty
`launch/tool.launch.py`. They expose no joint `6`, spawn no gripper controller,
and hardware bring-up omits the tool's servo group. The configurator uses
`servo_count` only for its estimated actuator cost.

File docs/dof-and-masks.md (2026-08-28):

# DOF and `dof_mask` — what the arm can and cannot do

Measured against the live base101 + mod101 sim on 2026-08-24, with
`robocore.kinematics` at engine@pending. Every number here came from the
robot, not from reasoning about the wrist. That distinction is the whole
point of this document: the first `dof_mask` written for this arm was
argued from its shape and was **wrong** — see
[Trap 1](#trap-1-reasoning-from-the-wrist).

---

## 1. What `dof_mask` is

A group's `dof_mask` is six flags, `[x, y, z, rx, ry, rz]`, saying which
Cartesian degrees of freedom `kin.ik` should **constrain**. A `0` means
"leave this free — the chain cannot choose it independently, so do not
pretend otherwise".

```yaml
groups:
  arm:
    dof_mask: [1, 1, 1, 1, 1, 0]     # position + roll + pitch; yaw free
```

It exists because an arm with fewer than six joints has a reachable set of
fewer than six dimensions. Ask such an arm to hold a fully specified pose
and there is generally no solution. Two bad things can happen if the mask
is absent or wrong:

- **too many constraints** — `ik` raises `Unreachable` for poses the arm
  could perfectly well reach;
- **the wrong axis freed** — `ik` silently solves a different problem than
  the mission asked, and the error shows up as a tool that is off by a few
  degrees in a way nothing reports.

Neither crashes. That is why this is worth writing down.

---

## 2. The chain

Five joints, read off `/controller_manager` and `/robot_description`:

| joint | axis | limits (rad) | contributes |
|---|---|---|---|
| `arm_joint_base` | +z | −1.571 … 1.571 | slews the whole arm |
| `arm_joint_shoulder` | +y | −0.001 … 3.142 | pitch |
| `arm_joint_elbow` | −y | −0.001 … 3.142 | pitch |
| `arm_joint_wrist_tilt` | −y | −1.230 … 1.540 | pitch |
| `arm_joint_wrist_roll` | +x | 0.000 … 3.142 | roll about the tool axis |

Tip: `arm_wrist_flange` (the tool mount — the jaws are modelled but have
no grasp-point frame, see `found_along_the_way.md` item 7).

Note the shape: **one yaw joint, three pitch joints, one roll joint.**

---

## 3. What it can and cannot do — measured

Take a pose the arm is known to hold (`q = [0.3, 1.0, 1.2, 0.2, 0.5]`),
perturb one axis at a time, and try to solve it with **all six** DOF
constrained.

| perturbation | 0.02 / 0.1 | 0.05 / 0.2 | 0.1 / 0.4 | 0.8 |
|---|---|---|---|---|
| **x** (m) | UNREACHABLE | UNREACHABLE | UNREACHABLE | — |
| **y** (m) | UNREACHABLE | UNREACHABLE | UNREACHABLE | — |
| **z** (m) | ok | ok | ok | — |
| **roll** (rad) | ok (5e-05) | ok (3e-07) | ok (2e-05) | ok (5e-06) |
| **pitch** (rad) | ok (2e-05) | ok (7e-04) | ok (2e-04) | ok (1e-04) |
| **yaw** (rad) | UNREACHABLE | UNREACHABLE | UNREACHABLE | UNREACHABLE |

With the profile's mask applied (`rz` free) the same perturbations all
succeed:

| perturbation | result |
|---|---|
| x, y, z ±0.02 … ±0.10 m | all ok |
| roll, pitch ±0.2, ±0.5 rad | all ok |

**So: the arm commands position and tool roll/pitch freely. It cannot
choose yaw.**

The physical story is one sentence: *the base joint that aims the arm at a
target is the same joint that sets the tool's yaw*, so the two are not
independent. Point at something to the left and the tool faces left; there
is no second joint to undo that.

---

## 4. The subtlety: the deficiency is not axis-aligned

`dof_mask` has one flag per axis, which quietly assumes the
uncontrollable direction *is* an axis. It is not. Taking the left singular
vector of the smallest singular value of the Jacobian — the direction in
which the tool cannot be moved at all:

| configuration | vx | vy | vz | wx | wy | wz |
|---|---|---|---|---|---|---|
| zero (stowed) | −0.000 | **+0.992** | −0.000 | +0.000 | −0.000 | −0.128 |
| folded forward | −0.000 | **+0.979** | +0.000 | +0.000 | +0.000 | −0.205 |
| mid workspace | −0.286 | **+0.926** | −0.000 | +0.092 | +0.028 | −0.227 |
| reaching out | −0.000 | **+0.973** | −0.000 | −0.165 | −0.000 | −0.161 |

It is dominated by **lateral translation (vy)** with a yaw (wz) component,
and it rotates as the arm moves.

So why mask `rz` and not `y`?

Because the mask decides *what the mission may command*, and a mission
wants to command position. Freeing `rz` gives the solver exactly one
degree of slack, which it spends absorbing the vy–wz coupling — and the
result is that x, y, z, roll and pitch are all achievable (§3, second
table). Freeing `y` instead would give up commanding lateral position,
which is the thing you actually care about, to keep a yaw you cannot use.

**`dof_mask` is therefore an approximation, chosen for what it buys the
caller — not a description of the null space.** For this arm the
approximation is exact enough that everything else becomes reachable. On a
robot where it is not, the honest answer is a tighter mask and a mission
that checks `kin.reachable()` rather than assuming.

---

## 5. Singularities

`kin.manipulability` over sample configurations, masked to the five
controllable DOF — see [Trap 3](#trap-3-manipulability-on-a-sub-6-dof-arm):

| configuration | rank | manipulability | smallest σ | singular values |
|---|---|---|---|---|
| zero (stowed) | 5 | 0.000816 | 0.0224 | 1.749, 1.008, 1.000, 0.161, 0.022 |
| folded forward | 5 | 0.006766 | 0.1271 | 1.758, 1.022, 1.000, 0.145, 0.127 |
| mid workspace | 5 | 0.008310 | 0.1251 | 1.767, 1.191, 0.798, 0.175, 0.125 |
| reaching out | 5 | 0.001601 | 0.0501 | 1.750, 1.316, 0.544, 0.159, 0.050 |
| elbow straight | 5 | 0.000769 | 0.0224 | 1.748, 1.220, 0.728, 0.161, 0.022 |

Rank never drops below 5 in normal use — this arm has no interior
singularity that costs it a whole degree of freedom. What it has is
**near-singular configurations**: stowed and elbow-straight both fall to
σ_min ≈ 0.022, an order of magnitude below mid-workspace. Those are the
configurations where a small Cartesian velocity demands a large joint
velocity.

Practical rule: **manipulability above ~0.005 is comfortable; below
~0.001 the arm is near the edge of its workspace or folded on itself.**
Stowed (all zeros) is the worst of the sampled set, which is worth knowing
because it is where the arm starts.

For a `Controller.STREAM` session this is the number to watch. It is not a
guarantee — the server-side joint velocity clamps are (spec §21, §26.5).

---

## 6. Reach envelope

`kin.reach()` reports **0.711 m**, which is the summed link extension —
an upper bound, not a promise. What is actually solvable, sweeping
`y = 0` with the profile mask:

| height | reachable x |
|---|---|
| z = 0.25 m | 0.15 … 0.50 m |
| z = 0.35 m | 0.15 … 0.45 m |
| z = 0.45 m | 0.05 … 0.40 m |
| z = 0.55 m | 0.00 … 0.35 m |

The inner limit is the arm folding back into its own base; the outer is
extension. Higher targets must be closer in — the envelope leans back as
it rises, which is what you would expect from an arm on a deck.

A slice at z = 0.35 across y (`#` reachable, from
`examples/27_kinematics.py`):

```
y=+0.30  .#######.....
y=+0.15  .#########...
y=+0.00  ...#######...
y=-0.15  .#########...
y=-0.30  .#######.....
         x=0.00 ......... 0.60
```

Symmetric, as it must be, with the hole at `y=0` where the arm cannot fold
back far enough.

**The `workspace:` box in the profile is `x [-0.15, 0.55] y [-0.45, 0.45]
z [0.20, 0.85]`, which is deliberately conservative and NOT this
envelope.** It is a safety clamp sized so nothing inside it hits the
chassis. **Enforcement is a Phase 7 item** ("Safety at rate: joint/
velocity clamps, FK workspace box") — not 6.4, which an earlier version of
this file got wrong — so the box is inert today and has not been tightened
against the numbers above.

---

## 7. Determining the mask for a new robot

Do not reason from the wrist. The recipe:

1. Get the arm to a **general** configuration — not stowed, not straight,
   nothing at a limit. A degenerate pose makes everything look coupled.
2. `target = kin.fk(group, q=q0)`. This pose is reachable by construction,
   so it is useless as a test on its own (see
   [Trap 2](#trap-2-testing-with-a-pose-that-came-from-fk)).
3. Perturb **one axis at a time** by a few centimetres or a few tenths of
   a radian and solve with `mask=[1]*6`. Record which perturbations raise
   `Unreachable`.
4. The axes that fail are the coupled ones. Free the **rotational** one
   the mission is least likely to need — freeing a translation gives up
   commanding position, which is almost never the right trade.
5. Confirm: with the candidate mask, every perturbation from step 3
   should now solve.
6. Sanity-check `np.linalg.matrix_rank(kin.jacobian(group, q=q0))`. It
   should equal the number of joints; if it is lower, the arm has a
   genuine internal singularity at that configuration and step 1 picked a
   bad pose.

`examples/27_kinematics.py` does steps 2, 3 and 5 for whatever arm it is
pointed at.

---

## 8. Traps

### Trap 1: reasoning from the wrist

The first mask written for this arm was `[1, 1, 1, 1, 0, 1]` — pitch
masked out — on the reasoning that a wrist with a single roll joint could
not independently pitch. Three of the five joints rotate about y, so pitch
is precisely what it *can* do. The mask was inverted from the truth for a
plausible-sounding reason, and nothing caught it for two tasks because
`dof_mask` was a field nobody read yet.

### Trap 2: testing with a pose that came from `fk`

A pose produced by `kin.fk(group, q=...)` is in the arm's own image, so it
solves with **all six** DOF constrained no matter how deficient the arm
is. A test built on one proves nothing about the mask. Perturb it first.

### Trap 3: manipulability on a sub-6-DOF arm

The textbook Yoshikawa measure is `sqrt(det(J · Jᵀ))`, which assumes at
least as many joints as task dimensions. With five joints and six rows,
`J · Jᵀ` is singular by construction and the measure returns **0.0 at
every configuration** — a number that reads as a permanent singularity and
means nothing. `kin.manipulability` computes over the rows `dof_mask`
selects, and raises rather than lying if more DOF are constrained than
there are joints.

### Trap 4: `reach()` is not the workspace

0.711 m is the sum of the link lengths. Nothing at that distance is
reachable in any useful orientation. Use `kin.reachable()` against real
targets.

---

## See also

- `engine/docs/api-reference.md` § Kinematics — the API surface
- `examples/27_kinematics.py` — all of the above, live
- `found_along_the_way.md` item 9 — how the wrong mask was found
- `robocore-api-v0.5-draft.md` §26 — the spec
- Decisions 28, 30, 31 in `robocore-implementation-plan.md`

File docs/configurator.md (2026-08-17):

# Configurator

`configurator/` is a self-contained static page + stdlib Python backend for
sizing, motoring, and tooling the arm. It edits the four build args in
`src/mod101_description/urdf/mod101_config.xacro` in place and shows a live three.js
view (`urdf-loader`) that re-renders on every save.

## Running

```bash
cd ~/robots/mod101
source /opt/ros/jazzy/setup.bash && source install/setup.bash   # for /urdf
python3 configurator/server.py
# open http://localhost:8001/
```

Backend (`server.py`) is stdlib-only Python — no Flask, no virtualenv.

## What you can change

The page's four inputs map 1:1 to the URDF's four xacro args:

| input | xacro arg | notes |
|---|---|---|
| **Shoulder / elbow motor** | `shoulder_mount` / `elbow_mount` | STS3215 / STS3250 → `small`; ST3120 → `big` |
| **Shoulder / elbow length** | `shoulder_ext_length` / `elbow_ext_length` | 2020 rail length, 80–280 mm |
| **Tool** | `tool` arg `default` | lists every `mod101_tool_*` package under `src/` |

Picking a **big** (ST3120) motor flips that joint's mount to `big`, which the
URDF and the payload model both treat as heavier servo body **plus** a fixed
downstream lever extension Δ (`delta_shoulder` / `delta_elbow`) — see the
integration spec, Part A3.

### Live readouts

- **Payload** — first-order static balance at the binding (bottleneck) pitch
  joint, for three duty regimes (Duty 70 % rated / Hold 50 % / Peak 100 %) ×
  two reaches (full / 70 %). The headline is duty-cycle at full reach, with the
  binding joint named. Both shoulder and elbow caps are shown so you can see
  which one limits.
- **Mass & reach** — uses **real printed masses** from `link_masses.json`
  (Part C, `tools/estimate_masses.py`) when present; falls back to lumped
  estimates with an "estimated masses" badge otherwise.
- **Estimated cost** — servo-only BOM (base 3215 · shoulder sel · elbow sel ·
  3× wrist/gripper 3215). Placeholder prices until the real BOM lands; **not** a
  purchase price.
- **Reference builds** — t-shirt presets **S** (dual-3250) / **M** (3120
  shoulder + 3250 elbow) / **L** (dual-3120) that set both motor dropdowns.

After changing anything, **Save** writes the four args. **Reload preview**
re-fetches `/urdf` into the 3D view (also auto-fires after Save and tool
changes), so edits to the xacro on disk show up without restarting. The preview
renders directly from `src/` via a temp ament overlay, so it reflects live edits
even if the colcon workspace isn't built or sourced. You can also open
`configurator/index.html` via `file://` for a read-only preview; Save and the
live `/urdf` view need the server.

## Endpoints

| Method + path | Purpose |
|---|---|
| `GET /load` / `POST /save` | the four build args (two lengths + two mounts) |
| `GET /collisions` | status of the background self-collision regen |
| `GET /masses` | `link_masses.json` (Part C output) or `{"masses": null}` |
| `GET /tool` / `POST /tool` | active tool + discovered tools |
| `GET /urdf` | runs `xacro` and rewrites mesh URIs to `/pkg/<pkgname>/meshes/<file>` |
| `GET /pkg/<pkgname>/meshes/<file>` | serves binary meshes from any package's `meshes/` dir |

`GET /tool` reads the `tool` xacro arg out of `mod101_config.xacro` and lists every
`mod101_tool_*` package under `src/`; `POST /tool` rewrites that arg's
`default`. If the arg is missing from `mod101_config.xacro`, both return HTTP 500 and
the page's tool dropdown comes up empty — that's the symptom to look for.

## Big-module alignment offsets

`urdf/modules/shoulder_big.xacro` and `elbow_big.xacro` each carry three
properties — `snx/sny/snz` and `enx/eny/enz` — that shift **all** of that
module's meshes together. Cosmetic only; kinematics are unchanged. They exist to
absorb a frame mismatch when the big parts come from a different CAD canvas than
the small ones.

These used to be editable over HTTP (`GET`/`POST /nudge`). That endpoint is
**removed** — it had no UI, and hand-editing the xacro is clearer than a
write-only API nobody could see the effect of. Edit the properties directly.

**They should be zero whenever the big parts are exported in the same frame as
the small ones.** Current state:

| Module | Offsets | |
|---|---|---|
| `shoulder_big.xacro` | `snx=0  sny=0  snz=0` | clean — same-frame export |
| `elbow_big.xacro` | `enx=0  eny=-0.002  enz=-0.006` | **non-zero** — 2 mm and 6 mm of shim |

A stale non-zero offset left over from an older export is indistinguishable, at a
glance, from a genuinely broken URDF: the whole assembly floats off the arm.
Before touching these, check the module's datums instead — the adapter's AABB
centre should sit on the extrusion axis, and the rotation link should be centred
on its joint axis. `shoulder_big.xacro` lists the exact numbers.

## Two buttons, because there are two costs

**Save to xacro** writes the five build values into `mod101_config.xacro`. It is
instant (~4 ms) and it does **not** rebuild anything.

**Rebuild MoveIt config** regenerates the self-collision matrices, at
`REGEN_TRIALS` (1,000,000) samples — about 20 s for all four tools. `POST
/collisions/regen`.

They were one button. That was wrong: it made a Save look cheap while quietly
running a *fast, under-sampled* regeneration (the generator's own 10,000 default),
which disables pairs that really can collide. Splitting them lets the rebuild be
slow and correct, and makes the cost something you choose rather than something
that happens to you.

`GET /collisions` reports `stale` — whether the generated matrices still carry
the same build stamp as `mod101_config.xacro`. That is read from the files
themselves, not remembered in the server, so it survives a restart and is still
right if you edit the xacro by hand. The UI uses it to mark the rebuild button as
owed.

**Switching tool does not make anything stale.** The generator writes one matrix
per tool on every run, all four stamped with the current rails and mounts, so
picking a different tool just selects an already-current file.

Neither button touches a robot that embeds the arm.

That is deliberate. An earlier version reached into a base101 workspace through a
`BASE101_WS` setting, which inverted the dependency: the arm had to know where
its consumers lived. That breaks as soon as there are two of them, one is on
another machine, or a consumer isn't base101 at all.

So each consumer owns its own regeneration, and the configurator only tells you
to run it — the `/save`, `/tool` and `/collisions` responses all carry a
`downstream` field with the instruction. For base101:

```bash
cd ~/robots/base101
./src/base101_arm/base101_arm_moveit_config/scripts/sync_arm_change.sh
```

That script sources the mod101 underlay (`MOD101_WS`, default `~/robots/mod101`)
so it reads the build args you just saved, then regenerates base101's chassis
matrices. Arguments pass through to its `gen_collision_matrix.py`.

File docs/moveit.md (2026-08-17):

# MoveIt 2

`mod101_moveit_config` gives the arm motion planning, collision-aware IK and
trajectory execution, in Gazebo or against mock/real hardware.

This is the reference: how it works, what to change, and what to do when it
breaks. **New to it? [moveit-getting-started.md](moveit-getting-started.md) is
the walkthrough** — install to first executed motion, about fifteen minutes.

```bash
sudo apt install ros-jazzy-moveit ros-jazzy-pick-ik

colcon build --symlink-install
source install/setup.bash

ros2 launch mod101_moveit_config demo.launch.py               # Gazebo + move_group + RViz
ros2 launch mod101_moveit_config demo.launch.py tool:=parallel
ros2 launch mod101_moveit_config mock.launch.py               # no Gazebo, no physics
```

Drag the interactive marker in RViz's MotionPlanning panel, **Plan**, then
**Execute**.

---

## The 5-DOF problem — read this first

mod101 has five actuated joints: base yaw (Z), then shoulder, elbow and
wrist-tilt, which are **all pitch joints about parallel ±Y axes**, then wrist
roll (X).

That reaches any position in the workspace, and it can pitch the tool up and
down. What it *cannot* do is choose the tool's azimuth independently — the
direction the tool points around vertical is whatever `joint_base` is set to.
A 6-DOF pose goal is therefore unsatisfiable except by coincidence. That is
geometry, not configuration: no solver setting fixes it.

MoveIt's default `KDLKinematicsPlugin` solves for full 6-DOF pose and needs at
least 6 joints. On this arm it fails or times out on essentially every goal,
which looks exactly like a broken install.

So `config/kinematics.yaml` uses **`pick_ik` with `rotation_scale: 0.0`** —
position-only IK. It solves for where the tool tip goes and accepts whatever
orientation results:

```yaml
arm:
  kinematics_solver: pick_ik/PickIkPlugin
  mode: global
  position_scale: 1.0
  rotation_scale: 0.0     # <- the accommodation
```

**Practical consequence: plan to positions, not poses.**

| In your code | Result |
|---|---|
| `set_position_target(x, y, z)` | works |
| joint-space goals | always work |
| `set_pose_target(pose)` | usually fails |

To *bias* the approach direction (e.g. prefer pointing down at a table), raise
`rotation_scale` to about **0.2–0.5** — a soft preference the solver trades off
against position. Do not set it to 1.0; that reproduces the KDL failure mode.
Grasps need their approach designed around the arm's fixed azimuth, not
specified as an arbitrary quaternion.

---

## The mental model

MoveIt knows nothing about your arm. It reads four descriptions, and everything
that goes wrong goes wrong in one of them.

| | Where | Answers |
|---|---|---|
| **Shape** | URDF | Where are the parts, and how far does each joint turn? |
| **Meaning** | SRDF | Which joints do I plan with, and what counts as a self-collision? |
| **Solver** | `kinematics.yaml`, `ompl_planning.yaml`, `joint_limits.yaml` | How do I turn a target into joint angles, and how fast may I move? |
| **Muscle** | `moveit_controllers.yaml` | Where do I send the finished plan? |

The chain runs one way — **configurator → URDF → SRDF → MoveIt**. Change
something near the front and everything behind it is stale until regenerated.
That is what [*When you change the build*](#when-you-change-the-build) is about.

## What's where

| File | What it is |
|---|---|
| `srdf/mod101.srdf.xacro` | Planning groups, named states, virtual joint. **Parametric** — takes `tool`, same as the URDF |
| `config/kinematics.yaml` | pick_ik, position-only (above) |
| `config/joint_limits.yaml` | Velocity/acceleration for time parameterisation. **No position limits** — those live in the URDF |
| `config/ompl_planning.yaml` | RRTConnect by default |
| `config/moveit_controllers.yaml` | Arm's FollowJointTrajectory handle. The tool contributes its own |
| `config/collisions/<tool>.srdf.xacro` | **Generated** self-collision matrices — see below |
| `test/moveit_smoke.py` | FK / IK / plan / execute checks; exits non-zero on failure |

Groups: **`arm`** (`base_link` → `wrist_flange`, 5 joints) and **`gripper`**
(the tool's joint `6`), with named states `home` / `ready` and `open` / `closed`.

The `arm` group deliberately terminates at `wrist_flange`, so it is identical
for every tool. Each tool contributes its own semantics from
`mod101_tool_<name>/srdf/tool.srdf.xacro`, the same way it contributes its URDF
and its ros2_control block — adding a tool stays a one-package job.

---

## When you change the build

The configurator writes four build args plus the active tool into
`mod101_description/urdf/mod101_config.xacro`. Everything downstream derives
from those five values.

**Save to xacro** writes those five values and nothing else — it is instant.
**Rebuild MoveIt config** is a separate button that regenerates the collision
matrices at 1,000,000 samples (~20 s for all four tools). The configurator marks
the rebuild as owed whenever the generated matrices no longer carry the same
build stamp as `mod101_config.xacro`.

> **A finished rebuild is not proof.** It reports `skipped: workspace not built`
> and carries on. Check `GET /collisions`.

> **If a robot embeds this arm, the configurator does not touch it.** mod101
> regenerates itself and nothing else — it deliberately doesn't know where its
> consumers live. Each consumer owns its own sync step, and the `/save` response
> carries a `downstream` note naming it. For base101:
>
> ```bash
> cd ~/robots/base101
> ./src/base101_arm/base101_arm_moveit_config/scripts/sync_arm_change.sh
> ```

### You changed a rail length — `shoulder_ext_length` / `elbow_ext_length`

The arm's reach changed, so *which link pairs can never touch* changed with it.
This is the case the generated matrices exist for.

| What | Status | Notes |
|---|---|---|
| URDF geometry | **rebuild** | xacro picks up the new args, but see the build-type note below |
| Collision matrices | **press Rebuild** | Save marks them stale; the Rebuild button regenerates all four tools at 1M samples |
| Payload / reach readout | **automatic** | Live in the configurator |
| Named poses `home` / `ready` | **check** | These are *joint angles*, not positions. Still legal, but a longer forearm means `ready` points somewhere else |
| Link masses | **re-run** | `python3 tools/estimate_masses.py` if you reprinted parts |

### You changed a servo bracket — `shoulder_mount` / `elbow_mount`

Picking an ST3120 flips that joint to the `big` mount: a heavier servo body
*and* a fixed downstream lever extension.

| What | Status | Notes |
|---|---|---|
| URDF geometry & inertia | **rebuild** | A different module file is included wholesale; ament_python means it needs a build |
| Collision matrices | **press Rebuild** | The lever extension shifts everything downstream |
| Joint *structure* | **unchanged** | `small` and `big` modules have identical link/joint graphs — only geometry differs |
| Velocity / acceleration caps | **edit** | `joint_limits.yaml` is hand-written and conservative. A bigger servo can take more; it will not raise itself |
| Travel limits | **recalibrate** | New bracket, new mechanical stops. See [calibration.md](calibration.md) |

### You changed the end effector — `tool`

Each tool is its own package with its own URDF fragment, SRDF fragment and
collision matrix. The SRDF picks the matching set with an `xacro:if`.

| What | Status | Notes |
|---|---|---|
| Tool geometry | **automatic** | Mount joint is always identity — see [tool-convention.md](tool-convention.md) |
| Gripper group & matrix | **automatic** | One matrix per tool already exists; the SRDF selects it |
| Planning group `arm` | **unchanged** | Terminates at `wrist_flange` |
| A brand-new tool package | **rebuild** | `colcon build` — a package that didn't exist can't be symlinked |
| Controllers | **check** | `tool:=none` has no actuated jaw, so no `gripper_trajectory_controller` is spawned |

### Why the matrices are generated

The URDF is parametric — rail lengths and the `small|big` mount swap move link
geometry around — so "which link pairs never collide" is a property of *your
build*, not of the design. A frozen matrix would either over-disable pairs on a
long-armed build (the planner drives the forearm through the base) or
under-disable on a short one (everything self-collides and nothing plans).

By hand:

```bash
python3 tools/gen_collision_matrix.py --trials 1000000
python3 tools/gen_collision_matrix.py --tool jaws --trials 1000000
```

Output has two parts:

- **Sampled pairs** — "never collides" decided by random search. Build-dependent.
- **Derived pairs** — emitted by `rigid_adjacency()` from the joint graph alone.
  Build-invariant. These exist because `collisions_updater` only marks *directly*
  connected links `Adjacent`: two links one hop apart across a **fixed** joint
  are never `Adjacent` and do collide when sampled, so they fall through both
  nets forever. That is the two halves of a hinge — and with the elbow's pair
  enabled, its range breaks into disconnected islands and OMPL cannot plan
  through it at all.

> **The trials trap.** "Never collides" is statistical, not a proof, and wrongly
> disabling a pair that *can* collide is the dangerous direction. At 10,000
> samples, measured on this build, `base_cover_1 ↔ wrist_camera_v1_1` was wrongly
> disabled for **all four tools** — the planner was free to drive the wrist
> camera through the base cover.
>
> The configurator's Rebuild button passes **1,000,000** and base101's generator
> defaults to it. But `gen_collision_matrix.py`'s own default is still **10,000**,
> so a hand-run without `--trials` produces the bad matrix. Always pass it.

> **`--symlink-install` does not cover the URDF.** Measured on a clean build:
> `ament_cmake` packages get their `share/` files symlinked back to `src/`, so
> edits are live — that is why `mod101_moveit_config`'s matrices and SRDF are.
> **`ament_python` packages get copies.** `mod101_description` and
> `base101_description` are both `ament_python`, so every `.xacro`, `.gazebo`
> and `.ros2control` edit needs `colcon build` before it reaches a launch. If a
> URDF change appears to do nothing, this is why.

## What never regenerates itself

Four things are hand-owned. Nothing in the pipeline touches them, and three of
the four have bitten.

| File | Holds | Watch for |
|---|---|---|
| `joint_limits.yaml` | Velocity and acceleration only | **Position limits are not here** — they live in the URDF |
| URDF `<limit>` tags | Real joint travel | A limit of exactly `0.0` is a trap — see below |
| `kinematics.yaml` | Solver choice, `rotation_scale` | Only touch it to constrain approach direction |
| SRDF group states | `home`, `ready` | Fixed joint angles. Still legal after a resize, but they no longer mean the same place |

---

## Controllers

MoveIt speaks `FollowJointTrajectory`; the plain sim's `arm_controller` and
`gripper_controller` are `JointGroupPositionController` and take
`Float64MultiArray`. Both sets claim the same joints, and `controller_manager`
allows only one active claim per joint.

So the MoveIt launches pass **`spawn_controllers:=false`** to
`gazebo.launch.py` (forwarded to the tool launch too) and bring up
`arm_trajectory_controller` + `gripper_trajectory_controller` instead. Nothing
is spawned and then switched away from — that ordering is racy and
`ros2 control switch_controllers` blocks when it loses the race.

| Bringup | Hardware | Controllers |
|---|---|---|
| `demo.launch.py` | Gazebo (`gz_ros2_control`) | JSB + arm/gripper trajectory controllers |
| `mock.launch.py` | `mock_components/GenericSystem` | same |
| `move_group.launch.py` | none — attaches to a running controller_manager | none |

`mock.launch.py` rewrites every `<ros2_control>` hardware plugin to
`mock_components/GenericSystem` before handing the description over. That
matters for `mod101_tool_pincopen`, which legitimately names the vendored
`pinc_open_driver/PincOpenDriver` for real hardware — without the rewrite, mock
bringup dies with a `LibraryLoadException` unless you've cloned that driver.

## Verifying an install

```bash
ros2 launch mod101_moveit_config mock.launch.py rviz:=false
# in another terminal:
python3 $(ros2 pkg prefix --share mod101_moveit_config)/test/moveit_smoke.py
```

Checks FK on `ready`, IK back to that pose (the 5-DOF question), that IK
*fails* on an unreachable pose, an OMPL joint-space plan, and execution all the
way through ros2_control. Current status: **5/5 on all four tools**, in both
Gazebo and mock.

---

## When planning fails

Each of these produces the same symptom — "planning failed" in RViz — and each
hides the next.

| Symptom | Cause | Fix |
|---|---|---|
| `NO_IK_SOLUTION` (−31) on every goal, even close ones | `pick_ik` isn't installed, or `kinematics.yaml` reverted to KDL | `sudo apt install ros-jazzy-pick-ik`; check `kinematics_solver: pick_ik/PickIkPlugin` |
| `pick_ik: Initial guess exceeds joint limits` | A joint is `type="continuous"` with no `lower`/`upper`, so there is no interval to sample | Make it `revolute` with real travel. Servo joints are never continuous |
| `CheckStartStateBounds failed … Start state out of bounds`, off by ~1e-13 | A limit sits at exactly `0.0` and the sim settles a picoradian below it | Give the stop ~1 mrad of margin (`lower="-0.001"`). `fix_start_state` does *not* help — it only normalizes continuous joints |
| `OMPL: Unable to solve the planning problem` after the full timeout, though start and goal are each valid | A self-collision splits a joint's range into disconnected islands | Regenerate the matrices; sweep the joint and check validity across its range |
| `CONTROL_FAILED` (−4) — plans fine, won't move | Trajectory controllers aren't up | `ros2 control list_controllers` — you want `arm_trajectory_controller` **active**, not `arm_controller` |
| Everything silent, `/joint_states` empty | Controller spawners lost a startup race and died | Check for `Configured and activated` on all of them. Faster boots make this likelier |

> **The one diagnostic worth knowing.** When a plan fails but the start and goal
> both look fine, sweep the suspect joint through its range and ask
> `/check_state_validity` at each step. A joint whose valid range comes back in
> disconnected bands cannot be planned through, no matter how good the endpoints
> are.

## Known rough edges

- **move_group segfaults on Ctrl-C.** In `~TrajectoryExecutionManager` during
  `rclcpp` teardown — an upstream MoveIt 2.12 / rclcpp shutdown bug. Harmless:
  it happens after everything has already stopped.
- **Collision meshes are the full-resolution visual STLs**, up to 7.3 MB
  (`servo_shoulder_big_1.stl`). Planning is fine at the current 167 disabled
  pairs (tool=jaws, of 276 total), but convex hulls would make collision
  checking materially cheaper — and would help Gazebo too.
- **Joint limits are partly measured.** `joint_wrist_tilt` (−1.23 … 1.54) and
  `joint_wrist_roll` (0 … π) are bounded `revolute`; the shoulder and elbow
  carry a −0.001 margin below their zero hard stop. The remaining estimates are
  the *dynamics* in `joint_limits.yaml`. See [calibration.md](calibration.md).
- **The tool joint is named `6`.** Legal, but it has to be quoted in every YAML
  and reads badly in SRDF. Renaming it to `joint_gripper` would touch all four
  tool packages.

---

Related: [performance-notes.md](performance-notes.md) for measurements and the
DDS traps · [ros-architecture.md](ros-architecture.md) for the package layout and
joint table · [worklogs/moveit.md](worklogs/moveit.md) for the original handover
note and the collision-matrix measurements that led here.

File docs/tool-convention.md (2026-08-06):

# Tool URDF convention

Every `mod101_tool_*` package follows the same coordinate convention so tools are interchangeable, the configurator's preview lines up cleanly, and the wrist adapter bracket has a single well-defined geometry.

## The rule

> **A tool's root link sits at the bolt pattern that mates with `wrist_flange`, oriented "upright" and projecting outward.**

Concretely, in the tool's root-link frame:

| Axis | Direction |
|---|---|
| `+X` | **outward** — the direction the tool projects away from the wrist (aligned with the wrist-roll axis) |
| `+Y` | right (when looking at the gripper from behind, along +X) |
| `+Z` | **up** — matches world `+Z` when the arm is in its canonical horizontal "pointing forward" pose |
| origin `(0,0,0)` | the geometric center of the bolt pattern that contacts `wrist_flange` |

This is a right-handed frame with `+X` as the "long" axis of the tool. A parallel gripper opens in `±Y`; a single jaw rotates in the `XZ` plane.

## What this means for the mount joint

The fixed joint that attaches the tool to the arm is **always identity**.
Tool URDFs are macros (so the arm can be instantiated multiple times in one
robot), so every link/joint name and reference carries the `${prefix}`
macro param:

```xml
<joint name="${prefix}<tool>_mount" type="fixed">
  <origin xyz="0 0 0" rpy="0 0 0"/>
  <parent link="${prefix}wrist_flange"/>
  <child  link="${prefix}<tool>_root_link"/>
</joint>
```

If the tool has a mounting adapter / spacer bracket, model that as part of the tool — either with its own link or by offsetting the body link inside the tool's URDF. Don't bake adapter geometry into the mount joint.

## What this means for visual origins

If you author a tool from scratch, place each mesh so the link origin coincides with the link's natural pivot point (or the bolt pattern, for the root link). Visual `<origin>` should usually be near zero — large offsets are a sign that the mesh was authored in a different CAD-assembly frame and is being shimmed into place.

If you vendor a tool from another project (`jaws` from LLMy, `pincopen` from CNURobotics, etc.), the source URDF will typically have one of:

- **All meshes authored at a common CAD-world origin**, with each link's `<visual><origin>` carrying a large negative offset that brings the meshes back to that common point. (LLMy / SO-101 are like this.)
- **Each mesh authored at its own link origin**, with `<visual><origin>` near zero. (PincOpen is like this.)

For the first case, encode the CAD-frame-to-tool-frame transform as a **single fixed joint inside the tool** between the convention root link and the vendored sub-tree:

```xml
<link name="<tool>_root_link"><inertial>tiny</inertial></link>  <!-- convention origin -->

<link name="<tool>_vendor_body"> ...mesh with original visual_origin... </link>

<joint name="<tool>_vendor_to_root" type="fixed">
  <origin xyz="..." rpy="..."/>   <!-- bake CAD-frame offset + rotation here -->
  <parent link="<tool>_root_link"/>
  <child  link="<tool>_vendor_body"/>
</joint>
```

That keeps the vendored sub-tree internally consistent with its source URDF (preserving inter-mesh geometry, joint pivots, dynamics) while exposing a clean convention-following root link to the arm.

## Joint naming

The active joint(s) inside a tool continue mod101's joint numbering: `6`, `7`, … (always written `${prefix}6` etc. in the macro — the standalone arm's prefix is empty, so the runtime name is just `6`; in a multi-arm robot it becomes e.g. `left_arm_6`). Stick to integer joint names for the active DOFs; descriptive names (`gripper`, `wrist_roll`) only for fixed cosmetic joints or `<mimic>` followers. `<mimic joint=...>` references must carry the prefix too.

The primary controller a tool exposes should be named `gripper_controller` regardless of internal joint name, so downstream code that publishes to `/gripper_controller/commands` is tool-agnostic. (Multi-arm integrators define their own prefixed controllers — e.g. `left_gripper_controller` on `left_arm_6` — in their controller YAML.)

## Checklist for a new tool

- [ ] `urdf/tool.urdf.xacro` defines `<xacro:macro name="mod101_tool_<name>" params="prefix:='' use_sim:='true'">`; every link/joint name and parent/child/mimic reference inside carries `${prefix}`. (Copy `mod101_tool_jaws` — smallest complete example.)
- [ ] Root link `${prefix}<tool>_root_link` exists, mount joint to `${prefix}wrist_flange` is identity.
- [ ] In the root frame: `+X` outward, `+Z` up, origin at the bolt pattern.
- [ ] Active joint is named `${prefix}6` (or next available integer).
- [ ] Controllers YAML exposes `gripper_controller`.
- [ ] `launch/tool.launch.py` spawns `gripper_controller` on a `TimerAction(10s)` so it runs after the arm's broadcaster + arm_controller.
- [ ] `urdf/tool.ros2control` defines `mod101_tool_<name>_ros2control(prefix, use_sim)` and switches hardware plugin on `${use_sim}` (`gz_ros2_control/GazeboSimSystem` vs. real driver); the `<ros2_control>` system name is `${prefix}mod101_tool_<name>_system`.
- [ ] One include + `<xacro:if>` invocation branch added to `mod101_macro.xacro`; one `<parameters>` branch in `mod101.xacro`'s plugin block (if the tool ships controllers).

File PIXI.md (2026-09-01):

# Running mod101 with pixi

[pixi](https://pixi.sh) gives you a complete ROS 2 Jazzy toolchain in a project-local
folder, pulled from the [RoboStack](https://robostack.github.io) conda channel. No
`apt`, no `/opt/ros`, no system-wide install - delete `.pixi/` and it's gone.

This is the fastest way to build and run the workspace on a dev machine. The
`docker/` stack is still the reference for the bench simulation and for the real
robot; see [`docker/`](docker/) for that.

## Install pixi

```bash
curl -fsSL https://pixi.sh/install.sh | bash
exec $SHELL          # pick up the PATH change
```

## Quick start

```bash
pixi install         # solve + download ROS 2 Jazzy (first run: a few minutes)
pixi run build       # colcon build the workspace
pixi shell           # enter the environment - workspace overlay included
pixi run sim         # ros2 launch mod101_harness sim.launch.py
```

`pixi run <task>` runs a single command in the environment and exits. `pixi shell`
gives you an interactive shell with `ros2`, `rviz2`, `colcon`, etc. on `PATH` and
the built workspace sourced. Leave it with `exit`.

## Environments

| Environment | Enter with | Contents |
|---|---|---|
| `default` | `pixi shell` | Bench sim: description, `ros2_control`, Gazebo, the `ros_gz` bridges |
| `full` | `pixi shell -e full`  | `default` + MoveIt 2 (`moveit`, `pick_ik`) + camera drivers (`realsense2_camera`, `usb_cam`, image transports) |

The split mirrors `docker/Dockerfile`: the bench sim never plans or looks through a
camera, so MoveIt and the RealSense stack are opt-in. Run planning demos or
`mod101_hw_bringup` from `-e full`.

Prefix any task with `-e full` too: `pixi run -e full build`.

## Tasks

Defined in `pixi.toml` under `[tasks]`:

| Task | Command |
|---|---|
| `pixi run build` | `colcon build --symlink-install --cmake-args -DCMAKE_BUILD_TYPE=Release` |
| `pixi run test` | `colcon test && colcon test-result --verbose` (builds first) |
| `pixi run clean` | `rm -rf build install log` |
| `pixi run sim` | `ros2 launch mod101_harness sim.launch.py` |
| `pixi run configurator` | `python configurator/server.py` - the web configurator on :8001 |

Anything not listed still works inside `pixi shell` / `pixi run --`:

```bash
pixi run -- ros2 launch mod101_moveit_config demo.launch.py     # needs -e full
pixi shell -e full
```

## How the workspace overlay works

`pixi.toml` registers `pixi/activate.sh` as an activation script. Every time you
`pixi shell` or `pixi run`, it sources `install/setup.sh` **if it exists**. So:

- Before the first `pixi run build` it's a no-op - the environment still works,
  you just can't `ros2 run` the mod101 packages yet.
- After a build, the overlay is live automatically. No manual `source install/setup.bash`.

Re-run `pixi run build` after changing any `CMakeLists.txt`, `package.xml`, or C++
source. `--symlink-install` means Python and launch/config edits are picked up
without a rebuild.

## Gotchas

- **Don't mix with system ROS.** Never `source /opt/ros/jazzy/setup.bash` inside a
  pixi shell - the combined `PYTHONPATH` breaks both. Close other ROS terminals
  *before* `pixi shell`. (The `configurator` section of the README tells you to
  source `/opt/ros`; use `pixi run configurator` instead when you're on pixi.)
- **Gazebo needs a GPU + display.** Same as the Docker stack: no headless mode. On
  a machine with an NVIDIA card make sure `glxinfo` works; if the Gazebo window
  won't open over X, run `xhost +local:` once.
- **`ROS_DOMAIN_ID`.** The Docker bench isolates itself on domain 1 with
  `ROS_AUTOMATIC_DISCOVERY_RANGE=LOCALHOST`. pixi sets nothing - export those
  yourself if you're on a network with a real robot on the ROS graph.
- **Lockfile.** `pixi.lock` pins exact package versions and is committed. Commit it
  when you change dependencies so everyone resolves the same graph. `pixi install`
  regenerates it if `pixi.toml` is newer.

## Packages not on RoboStack

These are pulled from GitHub, not conda - clone them into `src/` as the main
README describes, then `pixi run build`:

- `st3215_manager`, `ros2_control_bridge` - the Feetech servo drivers (`mod101_hw_bringup`)
- `pinc_open_driver` - only for the PincOpen tool on real hardware (`mod101_tool_pincopen`)
- the robocore agent - ships as its own container image; not built here

## Platforms

`pixi.toml` lists `linux-64` only. To build on Apple Silicon or an ARM SBC, add the
platform and re-solve:

```bash
pixi workspace platform add osx-arm64      # or linux-aarch64
pixi install
```

RoboStack publishes Jazzy for all three. Gazebo GUI support on macOS is limited -
expect to use it for description/MoveIt work, not the full bench sim.

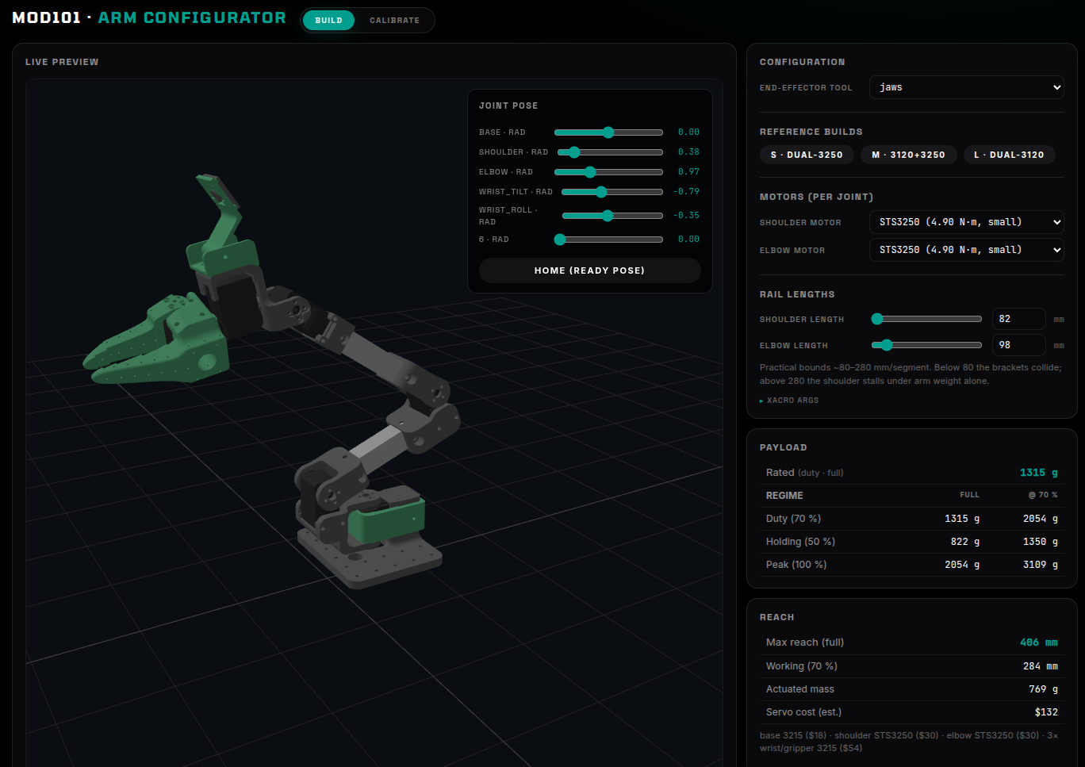
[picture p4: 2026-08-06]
img/configurator_static.png

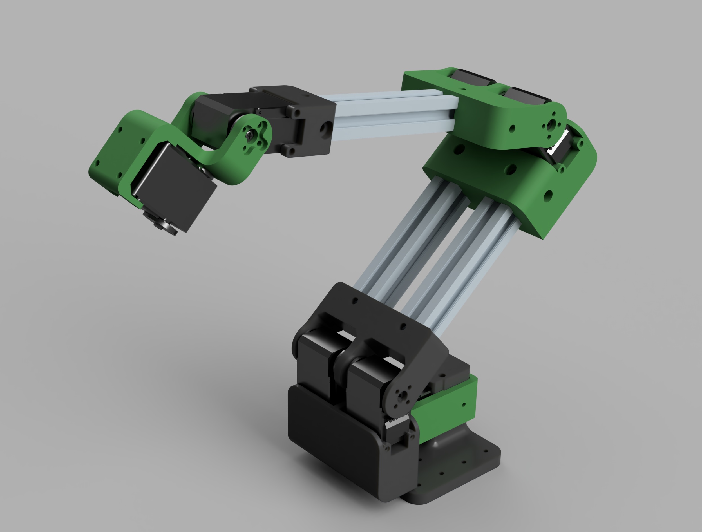
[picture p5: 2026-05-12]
img/imagine.jpg

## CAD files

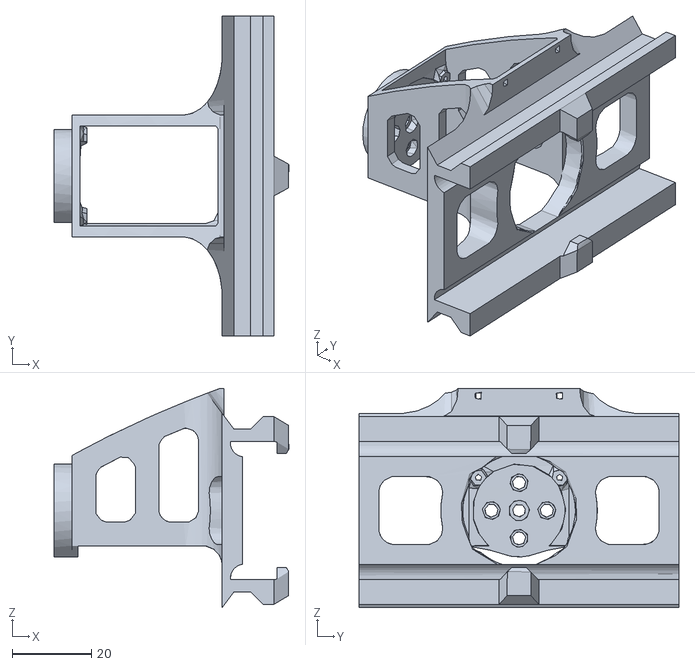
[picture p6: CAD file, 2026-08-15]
src/mod101_tool_parallel/meshes/Parallel_gripper_assembly_v1_1.stl
59.2 x 80.8 x 55.4

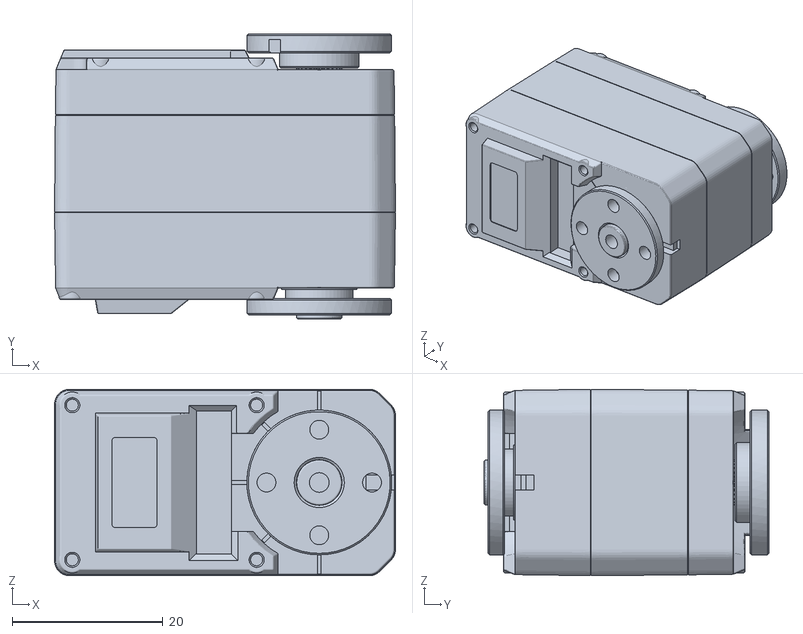
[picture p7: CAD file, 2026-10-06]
src/mod101_description/meshes/servo_wrist_pitch_7dof.stl
45.2 x 37.8 x 24.7

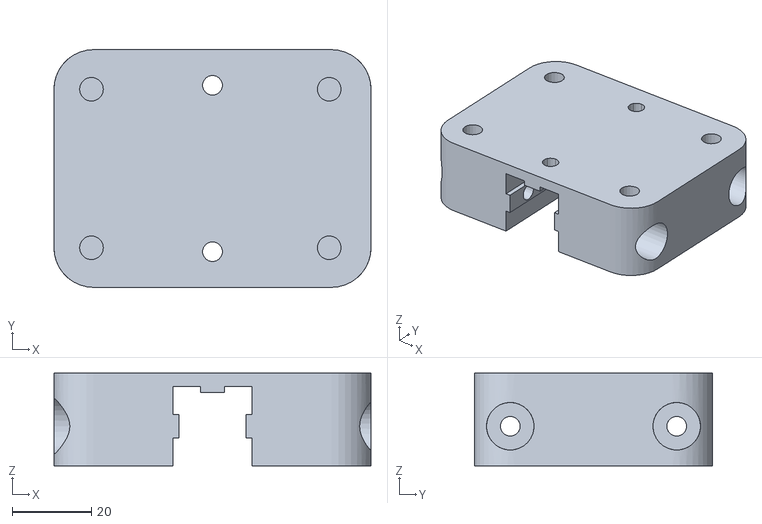
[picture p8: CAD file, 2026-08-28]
src/mod101_harness/meshes/mod_101_adapter_1.stl
80.0 x 60.0 x 23.4

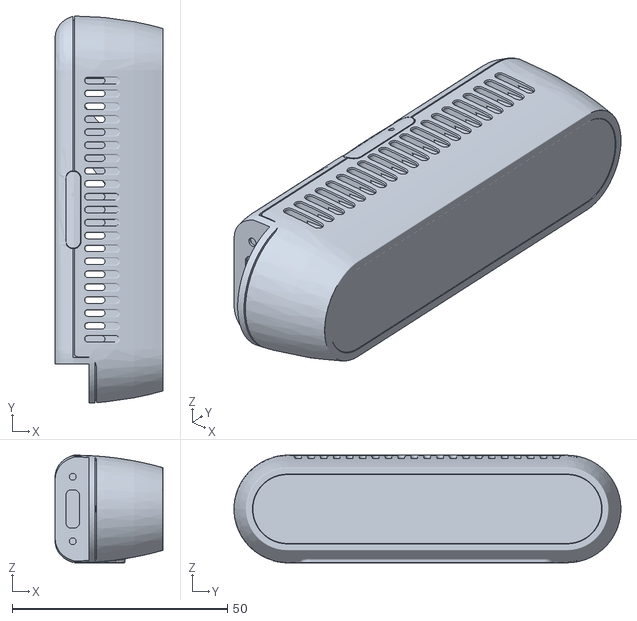
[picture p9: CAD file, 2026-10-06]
src/mod101_tool_camera/meshes/realsense.stl
25.1 x 89.9 x 25.0

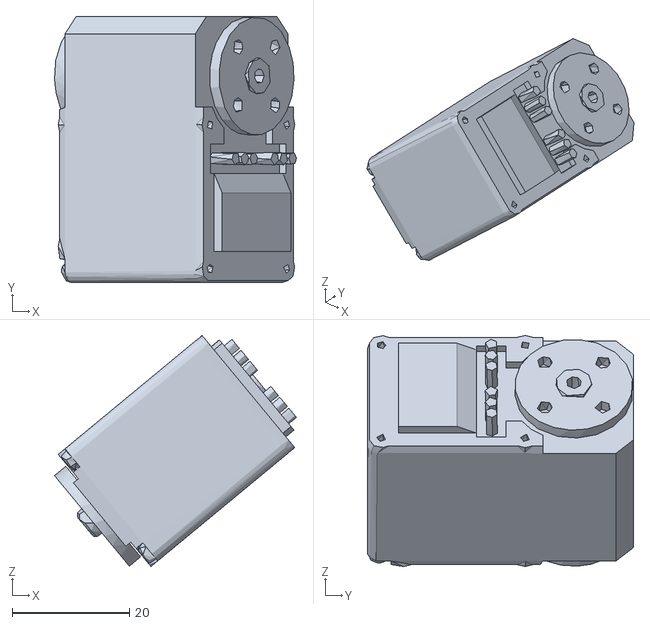
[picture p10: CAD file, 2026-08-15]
src/mod101_tool_jaws/meshes/arm_gripper_servo_1.stl
41.2 x 45.4 x 39.4

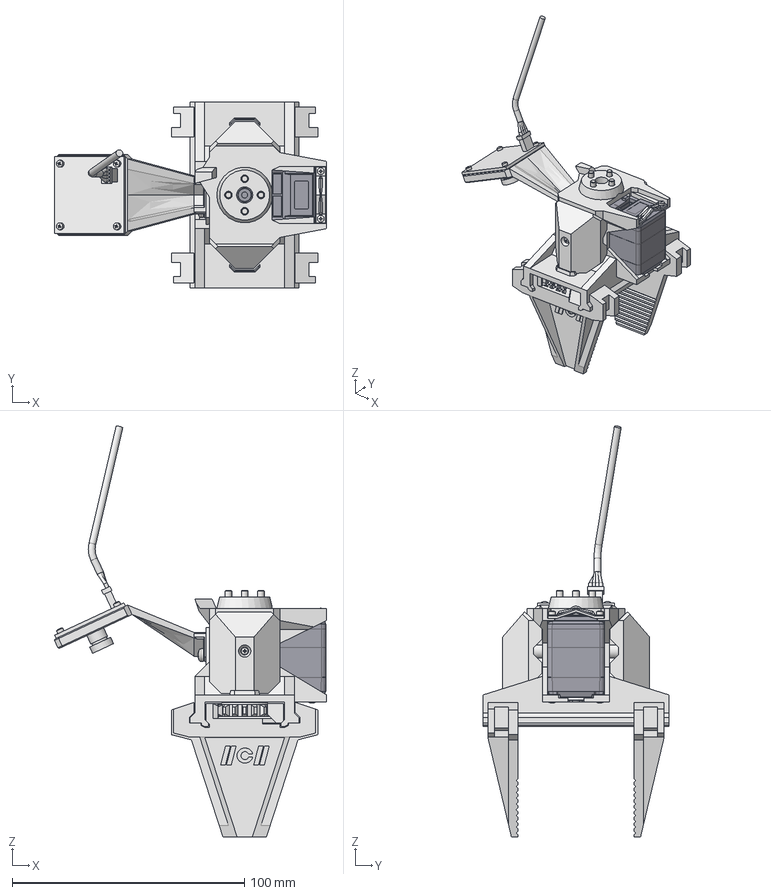
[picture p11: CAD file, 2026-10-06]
src/mod101_tool_pggripper/config/Gripper.stp
117.2 x 80.0 x 177.0 mm
Gripper_Base
Gripper Gear
Gripper_Jaw x 2
Gripper_Base_Shield x 2
CameraMount_square32mm
Wiring_bracket
UVC_Camera
Idler Horn
CRFHTSTATI ANSI B18.6.4 - 1-42 x 3/16 Steel Grade 2 Plain x 10
DIN EN ISO 7045 - M3 x 6 - H Steel 4.6 Plain x 11
Servo ST3215_1
Servo Horn

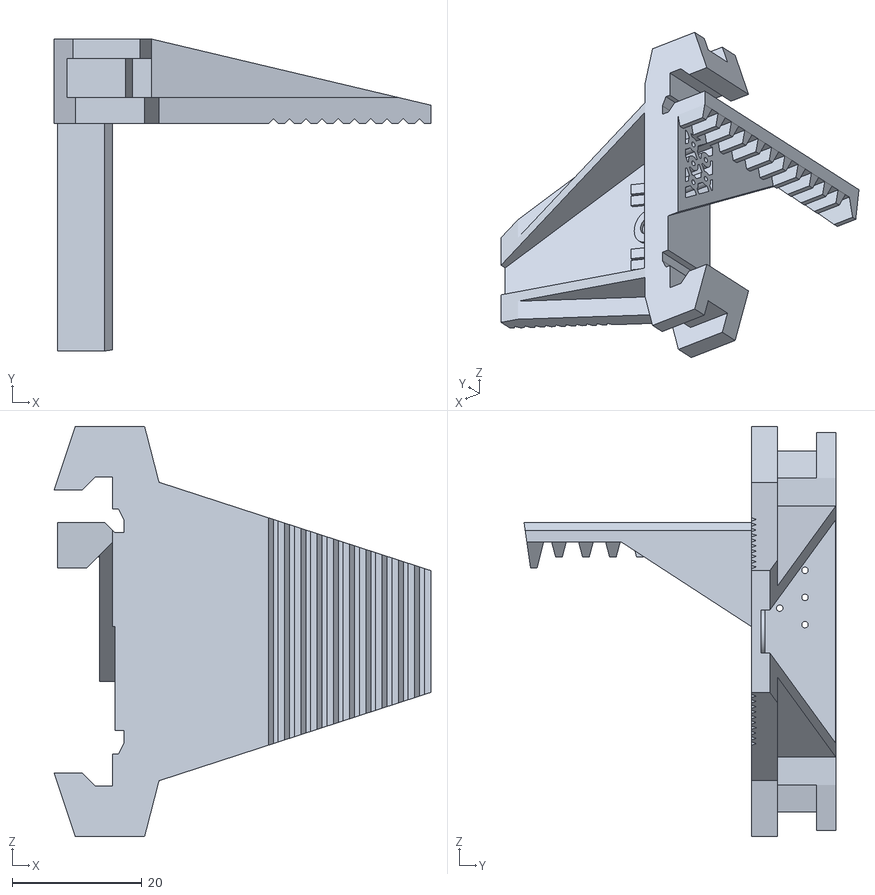
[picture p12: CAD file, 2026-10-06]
src/mod101_tool_pggripper/meshes/left_jaw.stl
58.0 x 48.0 x 63.1

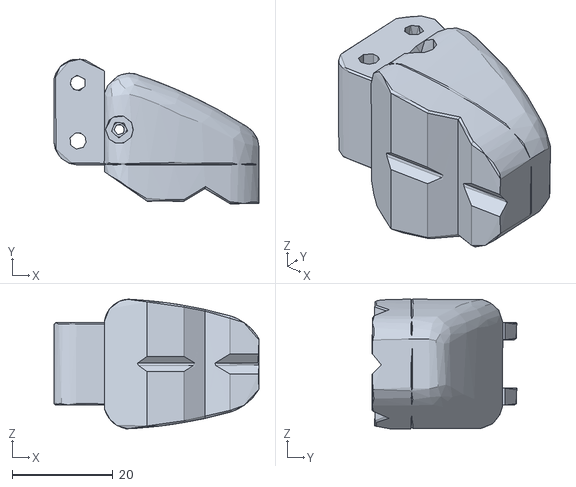
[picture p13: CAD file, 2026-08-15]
src/mod101_tool_pincopen/meshes/gripper_left_finger.stl
40.7 x 28.7 x 25.8

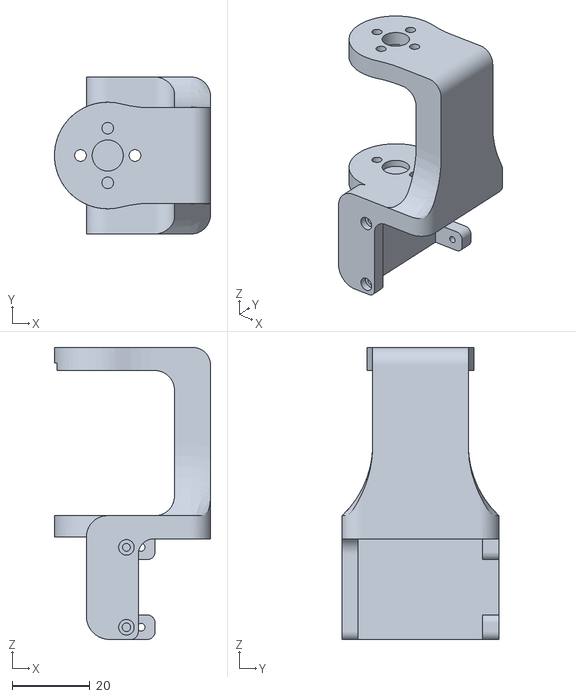
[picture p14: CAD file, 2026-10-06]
src/mod101_description/meshes/wrist_yaw_link_7dof.stl
40.1 x 40.3 x 75.0

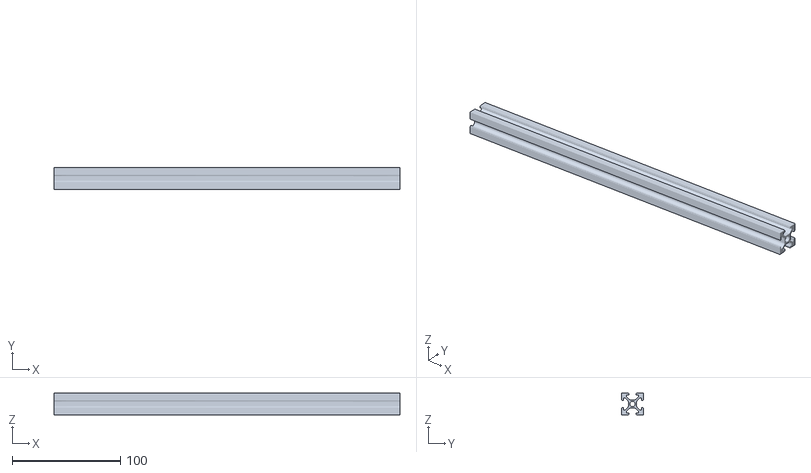
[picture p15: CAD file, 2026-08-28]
src/mod101_harness/meshes/base_link.stl
320.0 x 20.0 x 20.0

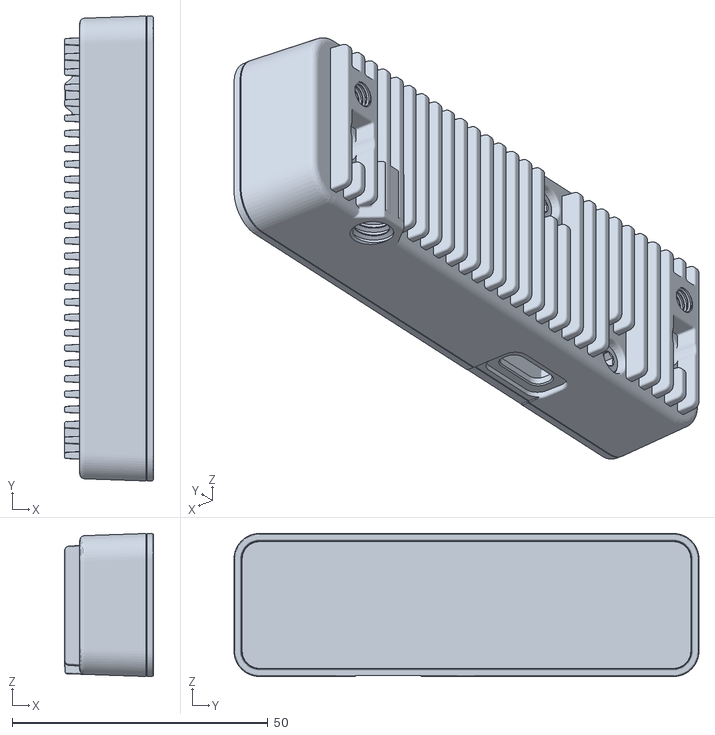
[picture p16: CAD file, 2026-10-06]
src/mod101_tool_camera/meshes/luxonis.stl
17.5 x 91.0 x 28.0

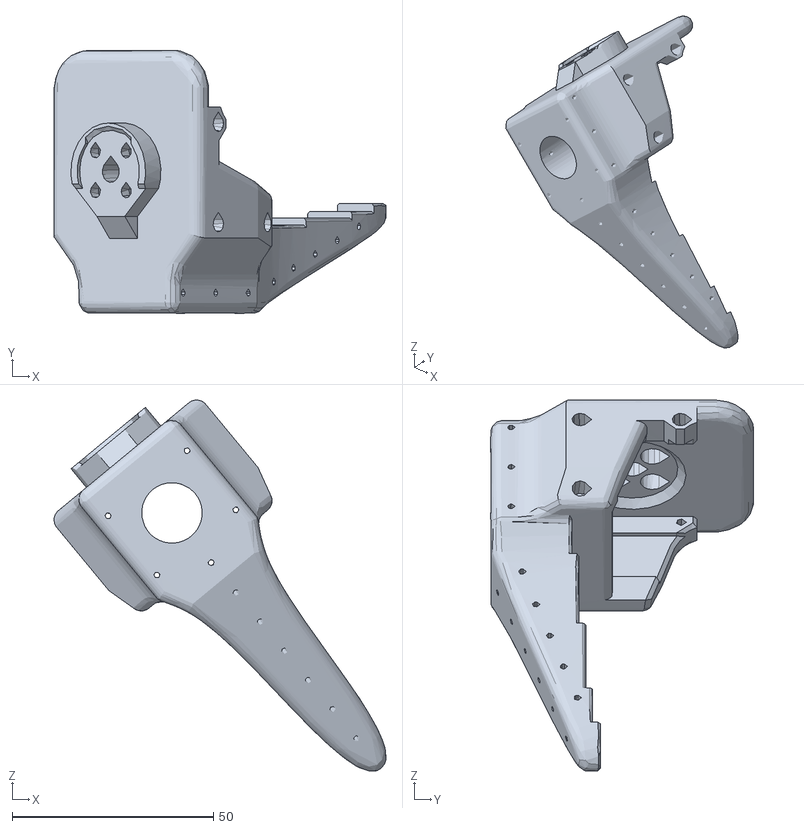
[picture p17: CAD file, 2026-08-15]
src/mod101_tool_jaws/meshes/Wrist_Roll_08c_v1_1.stl
82.4 x 65.2 x 92.1

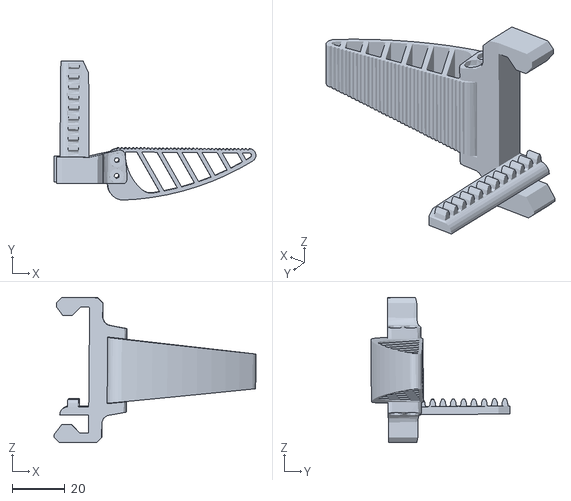
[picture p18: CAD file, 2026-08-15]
src/mod101_tool_parallel/meshes/right_jaw_v1_1.stl
76.8 x 53.0 x 55.3

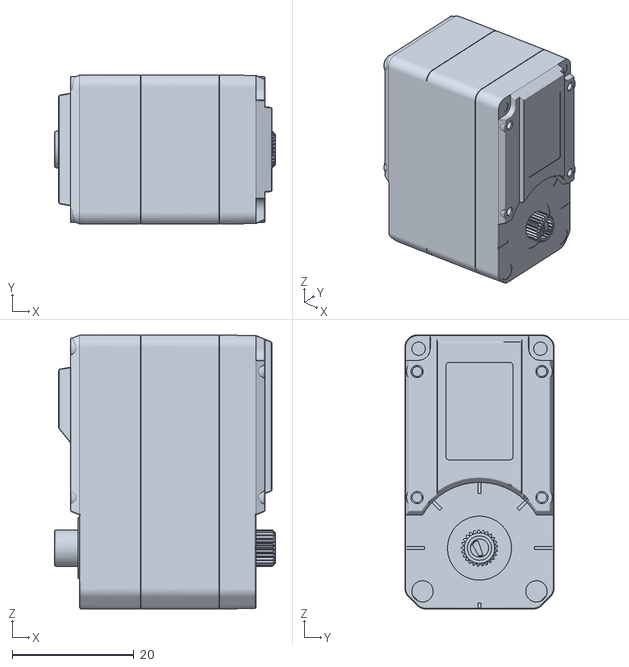
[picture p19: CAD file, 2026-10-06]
src/mod101_tool_pggripper/meshes/servo.stl
36.3 x 24.5 x 45.0

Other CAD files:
src/mod101_tool_parallel/meshes/parallel_servo.stl
src/mod101_tool_pincopen/meshes/gripper_left_arm_simple.stl
src/mod101_description/meshes/servo_wrist_yaw_7dof.stl
src/mod101_description/meshes/arm_extrusion_1.stl
src/mod101_description/meshes/base_cover_1.stl
src/mod101_description/meshes/base_link.stl
src/mod101_description/meshes/base_rotation_body_1.stl
src/mod101_description/meshes/big_elbow_servo_1.stl
src/mod101_description/meshes/camera_adapter_1.stl
src/mod101_description/meshes/camera_mount_1.stl
src/mod101_description/meshes/camera_tilter_1.stl
src/mod101_description/meshes/camera_wing_1.stl
src/mod101_description/meshes/elbow_adapter_1.stl
src/mod101_description/meshes/elbow_adapter_big_1.stl
src/mod101_description/meshes/elbow_extrusion_1.stl
src/mod101_description/meshes/elbow_fork_1.stl
src/mod101_description/meshes/elbow_link_1.stl
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

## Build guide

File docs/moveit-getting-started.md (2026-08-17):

# Getting started with MoveIt on mod101

From nothing to a planned, executed motion. About fifteen minutes, no hardware
required.

If you just want the reference — solver settings, the SRDF layout, controller
wiring — that's [moveit.md](moveit.md). This page is the walkthrough.

---

## 1. Install

You need ROS 2 Jazzy on Ubuntu 24.04 already working. Then:

```bash
sudo apt install ros-jazzy-moveit ros-jazzy-pick-ik
```

`pick_ik` is not optional. mod101 is a 5-DOF arm and MoveIt's default IK solver
cannot handle it — [step 5](#5-the-one-thing-that-will-confuse-you) explains
why. Installing MoveIt without it gives you a stack that fails every goal.

## 2. Build

```bash
cd ~/robots/mod101
colcon build --packages-select \
  mod101_description mod101_control mod101_gazebo mod101_moveit_config \
  mod101_tool_parallel mod101_tool_pincopen mod101_tool_jaws mod101_tool_none
source install/setup.bash
```

## 3. First launch — no physics

Start with mock hardware. It's fast, it runs on a headless box, and if
something is wrong you find out in ten seconds instead of waiting for Gazebo.

```bash
ros2 launch mod101_moveit_config mock.launch.py
```

Wait for this line:

```
You can start planning now!
```

That's move_group telling you the robot model, the SRDF and the planning
pipeline all loaded. If you don't get it, jump to
[troubleshooting](#troubleshooting).

### Check it properly

In a second terminal:

```bash
source ~/robots/mod101/install/setup.bash
python3 $(ros2 pkg prefix --share mod101_moveit_config)/test/moveit_smoke.py
```

```
PASS  FK on ready state — wrist_flange at (0.2350, 0.0742, 0.3592)
PASS  IK to reachable pose (position-only, 5-DOF) — position error 0.21 mm
PASS  IK correctly fails on unreachable pose
PASS  OMPL joint-space plan home -> ready
PASS  MoveIt executes through to ros2_control
5/5 passed
```

Anything less than 5/5 means the config is broken, not your code. It exits
non-zero, so it works as a CI gate too.

## 4. Move the arm

Still with `mock.launch.py` running, in the second terminal:

```bash
EX=$(ros2 pkg prefix --share mod101_moveit_config)/examples
python3 $EX/move_to_position.py 0.20 0.05 0.30
```

```
Moving: wrist_flange -> (0.2, 0.05, 0.3) in world, +/-10 mm
OK — planned and executed
```

That's the whole loop: plan, execute, arm moves. Add `--plan-only` to see the
plan without committing to it, and `--speed 0.1` to slow it down.

More points to try — all of these are reachable at the default rail lengths
except the last, which is deliberately out of range:

```bash
python3 $EX/move_to_position.py 0.15 0.10 0.25
python3 $EX/move_to_position.py 0.235 0.074 0.359    # the SRDF 'ready' pose
python3 $EX/move_to_position.py 3.0 0.0 0.5          # deliberately too far
```

The last one fails, as it should.

## 5. The one thing that will confuse you

**mod101 plans to positions, not poses.**

Its three pitch joints are parallel, so the arm can put the tool tip anywhere in
its envelope and pitch it up or down — but it cannot aim the tool sideways
independently. That direction is whatever `joint_base` is set to. A full 6-DOF
pose goal is unsatisfiable except by luck.

| In your code | Result |
|---|---|
| `set_position_target(x, y, z)` | works |
| joint-space goals | always work |
| `set_pose_target(pose)` | usually fails |

That's why `move_to_position.py` takes `x y z` and no orientation. It is geometry,
not configuration — no solver setting fixes it, though `rotation_scale` can turn
orientation into a soft preference.

**Why, and how to bias the approach direction:**
[moveit.md § The 5-DOF problem](moveit.md#the-5-dof-problem--read-this-first).

## 6. Now with physics and a GUI

```bash
ros2 launch mod101_moveit_config demo.launch.py
```

Gazebo, move_group and RViz together. In RViz's **MotionPlanning** panel: drag
the blue interactive marker to a goal, hit **Plan**, then **Execute**. The same
scripts from step 4 work against this too.

Pick your end-effector with `tool:=`:

```bash
ros2 launch mod101_moveit_config demo.launch.py tool:=parallel
ros2 launch mod101_moveit_config demo.launch.py tool:=pincopen
ros2 launch mod101_moveit_config demo.launch.py tool:=none
```

The gripper is its own planning group. Named states `open` and `closed` are in
the MotionPlanning panel's group dropdown.

## 7. If you changed the arm's dimensions

Rail lengths and mount sizes move link geometry around, which changes which link
pairs can actually collide. The self-collision matrix is generated, not
hand-written, so **regenerate it after any build change**:

```bash
python3 tools/gen_collision_matrix.py --trials 1000000
```

Skip this and you get one of two bad outcomes: pairs disabled that shouldn't be
(the planner drives the forearm through the base), or pairs enabled that
shouldn't be (everything reports self-collision and nothing plans).

The configurator's Save does this for you — for mod101 only. If you have a robot
that embeds the arm, it runs its own sync step. Full rules, including what
*doesn't* regenerate itself:
[moveit.md § When you change the build](moveit.md#when-you-change-the-build).

## Troubleshooting

The two you are most likely to hit first are below. The full table — including
the failures that look identical but aren't — is in
[moveit.md § When planning fails](moveit.md#when-planning-fails).

**Every goal fails with `NO_IK_SOLUTION` (-31) even for close points.**
`pick_ik` probably isn't installed, or `kinematics.yaml` got reverted to KDL.
Check `kinematics_solver: pick_ik/PickIkPlugin`.

**`CONTROL_FAILED` (-4), plans fine but won't move.**
The trajectory controllers aren't up. Confirm with:

```bash
ros2 control list_controllers
```

You want `arm_trajectory_controller` **active** — not `arm_controller`. The two
claim the same joints and only one may be active at a time; the MoveIt launches
handle this by passing `spawn_controllers:=false` to the Gazebo launch.

**Controllers fail to load, or spawners report "already loaded" then "no
controller with this name exists".**
Another ROS system is on your DDS domain, and the spawners are talking to *its*
controller_manager. Check with `ros2 node list` — if you see nodes you didn't
start, set `ROS_DOMAIN_ID` to something unused, or shut the other one down.

**`LibraryLoadException: pinc_open_driver/PincOpenDriver does not exist`.**
Only bites outside `mock.launch.py` (which rewrites hardware plugins to
mock_components). For real `tool:=pincopen` hardware you need
[CNURobotics/pinc_open_driver](https://github.com/CNURobotics/pinc_open_driver)
cloned into `src/`.

**move_group segfaults when you Ctrl-C it.**
Known upstream MoveIt 2.12 / rclcpp teardown bug, in `~TrajectoryExecutionManager`.
It happens after everything has already stopped. Ignore it.

**`Detected jump back in time. Clearing TF buffer.` on repeat.**
Something is publishing `/clock` twice. Gazebo's clock must have exactly one
bridge — `gazebo.launch.py` runs a dedicated `clock_bridge` node, so `/clock`
must *not* also appear in `mod101_gazebo/config/gz_ros_bridge.yaml`. Two
publishers sample Gazebo at different moments, sim time appears to step
backwards, and MoveIt's TF lookups break. Check with
`ros2 topic info /clock --verbose` — you want one publisher.

**Trajectories are absurdly fast or slow.**
`config/joint_limits.yaml` holds conservative estimates, not measured servo
data — the URDF's `velocity="100"` is placeholder CAD output. Tune there, and
see [calibration.md](calibration.md) for getting real numbers off the arm.

## Where to go next

- [moveit.md](moveit.md) — the reference: SRDF layout, solver tuning, how tools
  contribute planning semantics
- [ros-architecture.md](ros-architecture.md) — packages, controllers, the tool
  contract
- Adding a tool? It needs `srdf/tool.srdf.xacro` and
  `config/moveit_controllers.yaml` alongside the URDF — see
  [ros-architecture.md](ros-architecture.md#adding-a-new-tool)

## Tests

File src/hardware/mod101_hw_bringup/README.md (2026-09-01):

# mod101_hw_bringup

The mod101 arm on its camera-tower harness, on **real hardware**.

```bash
ros2 launch mod101_hw_bringup bringup.launch.py
```

This package is configuration, not code. Every node it starts comes from
somewhere else, and none of those places know what a mod101 is:

| what | package | where it comes from |
|---|---|---|
| Feetech ST3215 bus | `st3215_manager` | [robocore-labs/ros2_feetech_manager](https://github.com/robocore-labs/ros2_feetech_manager) |
| ros2_control hardware plugin | `ros2_control_bridge` | [robocore-labs/ros2_control_bridge](https://github.com/robocore-labs/ros2_control_bridge) |
| RealSense | `realsense2_camera` | upstream |
| wrist camera | `usb_cam` | upstream |
| description, controllers | `mod101_harness`, `mod101_description` | this repo |

The two robocore drivers are separate repos. Get them into the workspace with
`vcs import src/hardware < src/hardware/hardware.repos`, or symlink a local
checkout — see `hardware.repos`.

## The shape of it

```
  controllers                    ros2_control_node
  (arm / pan_tilt / gripper)            │
                                        │  ros2_control_bridge/TopicBridge
                                        ▼
        /motor_manager/arm_cmd   ┌──────────────┐   /motor_manager/joint_states
        /motor_manager/tool_cmd  │              │   ─────────────────────────▶
        /motor_manager/head_cmd  │ Float64Multi │        (back to the bridge)
        ────────────────────────▶│   Array      │
                                 └──────┬───────┘
                                        ▼
                                 servo_manager_node
                                        │
                                 one RS-485 chain, 8x STS3215
```

**Why the bus is a separate node instead of a SystemInterface that opens the
port.** `read()` and `write()` run inside controller_manager's update loop, so a
blocking serial read there stalls every controller on the robot — and eight
servos over one 1 Mbaud line is milliseconds per cycle. Splitting them puts the
serial latency on a topic instead of in the control loop. The cost is a hop and
the loss of hard sync between command and state, which a hobby servo bus does
not offer anyway.

## In a container

Parity with the sim stack, and the same shape: one image built from this repo,
one pulled for the agent.

```bash
docker compose -f docker/hardware.compose.yaml up --build
docker compose -f docker/hardware.compose.yaml down
```

**Run it this way rather than from a shell.** A `kill` on a host launch takes
the launcher and misses its `robot_state_publisher`, which keeps publishing
`/robot_description` and TF into the next run's graph; three of those piled up
here in one afternoon, and the symptom is a duplicate-node warning and TF that
flickers between two robots. `docker compose down` cannot leave one behind.

Three things the compose file gets right that are easy to get wrong by hand:

- **The bus is mapped by its udev name**, `/dev/mod101-servo`, which is what
  `servos.yaml` already names. The Link101 exposes five CDC endpoints and their
  numbering moves — it shifted once mid-session on this bench. Never map
  `/dev/ttyACMn`.
- **A different ROS domain from the sim** (2 vs 1). Sharing one would put a
  simulated `controller_manager` on the same graph as the real one, and a
  `ros2 topic pub` meant for the bench would reach the robot.
- **`restart: "no"`.** The driver refuses to start when motors are silent or a
  joint is resting outside its calibrated travel. Those want a person, not a
  supervisor retrying into them.

`up` starts three services: the robot, **ROSBoard** on
<http://localhost:8888>, and the agent on `ws://localhost:10101`.

**ROSBoard can move the arm.** The robocore fork's publish allowlist includes
`std_msgs/Float64MultiArray`, so its Joint sliders card publishes onto
`/arm_controller/commands` — and that controller treats what it receives as a
step, so a slider dragged across its range is a full-speed sweep with no
trajectory and no collision checking. It also binds `0.0.0.0:8888`, and with
`network_mode: host` there is no port mapping to narrow that: anything that can
reach this machine can drive the arm. On a bench that is what you want it for.

Its zero-on-silence watchdog deliberately skips position commands — a "safe"
zero is a stop for a Twist and a trip to home for a joint angle — so closing
the tab holds the arm rather than moving it.

The driver packages are cloned during the build, by the same `vcs import` line
a host workspace uses. So the image holds what is on `main` — a local edit that
has not been pushed does not silently become what the robot runs. The flip side
is that Docker cannot see a remote branch move, so after pushing a driver
change:

```bash
docker compose -f docker/hardware.compose.yaml build \
  --build-arg DRIVERS_CACHEBUST=$(date +%s)
```

Cameras are not wired into the image yet; see the note at the foot of
`hardware.compose.yaml`.

## Calibrate, then launch

The configurator writes everything that has to be discovered from the actual
robot, so a bring-up after calibration is one command:

```bash
python3 configurator/server.py     # Calibrate -> sweep each joint -> Write to repo
ros2 launch mod101_hw_bringup bringup.launch.py
```

**Three files make up the servo config, and which one owns what is the design:**

| file | written by | holds |
|---|---|---|
| `config/servos.yaml` | you | bus port, rates, which groups exist, speeds, accelerations, safety flags |
| `config/servos.generated.yaml` | the configurator | motor IDs, joint names, directions, array indices |
| `mod101_control/config/calibration.yaml` | the configurator | home tick and travel per joint |

`bringup.launch.py` loads the first, overlays the second, injects the third, and
hands the result to the driver as parameters.

**Two generated files rather than one big one, and neither is the authored
file.** A generator that rewrites `servos.yaml` eats the comments explaining why
the numbers are what they are — why the shoulder runs at half speed, why
`require_motors` is on — and those comments are the only record of it. Keeping
the machine's half separate means neither can clobber the other, and the overlay
only replaces the five keys it owns, so adding a tuning parameter to
`servos.yaml` needs no change to the generator.

**Group membership is read, not inferred.** The configurator asks `servos.yaml`
which joints belong to which group rather than sorting them by name — that
guessing is exactly what used to put the pan/tilt joints on the arm's topic. A
mapped servo whose joint no group claims, or a group joint with no servo, is a
warning in the write log, not a silent omission.

If the driver refuses a group with `min_ticks >= max_ticks`, the joint's travel
crosses the encoder's `4095 -> 0` seam. Recalibrate it in the configurator's
guided flow and, with the joint at its URDF default, press **Set centre here**
if the joint moves both ways from that pose (base, pan, tilt, wrist tilt) or
**Set zero here** if that pose is a hard stop (shoulder, elbow, wrist roll,
jaw). Either writes an offset into the servo placing the travel clear of the
seam; it is a servo-side fix, so it holds across power cycles and for this
driver too.

Without the calibration file the driver runs **uncalibrated**: home at mid-scale (2048) and
travel over the full encoder range. Every joint angle is then offset by however
far its servo horn sits from centre, in both directions at once — commands land
short and the reported position is wrong by the same amount, so the error
cancels on a plot and does not cancel on a robot. The launch says so loudly at
startup; it is not a silent default.

## Configuration

`config/controllers.yaml` — the same controller set as the sim, in one file,
with `use_sim_time: false`. There is no `/clock` here, and a controller waiting
for simulated time on a robot with no simulator never ticks.

**Three groups — `arm`, `tool`, `head` — and they are declared twice.** Once as
`<param name="group">` on each joint in the URDF (`mod101_harness_arm.xacro`,
`mod101_tool_jaws/urdf/tool.ros2control`), and once as a group block in
`servos.yaml`. The URDF side decides what the bridge publishes and in what
order; the YAML side decides which motor reads which index. **They have to
agree**, including the order of joints within a group, because that order *is*
the array layout on the wire. Reorder one side and the wrong servo moves.

## Arguments

| arg | default | |
|---|---|---|
| `hardware` | `bridge` | `mock` loops commands back as state — the whole graph comes up and nothing moves |
| `cameras` | `true` | `false` skips both cameras |
| `serial_port` | from yaml | override the bus device |
| `calibration_file` | `mod101_control/config/calibration.yaml` | |
| `servos_file`, `controllers_file`, `generated_servos_file` | this package | |
| `tool`, `shoulder_ext_length`, … | configurator's saved values | same build args as `sim.launch.py` |

A first bring-up worth doing in this order:

```bash
# 1. nothing moves, everything loads — checks the URDF, plugin and controllers
ros2 launch mod101_hw_bringup bringup.launch.py hardware:=mock cameras:=false

# 2. the bus, for real, with the arm powered
ros2 launch mod101_hw_bringup bringup.launch.py cameras:=false
```

## Cameras

`launch/cameras.launch.py`, also runnable alone. It **remaps the drivers onto
the topic names the simulator uses** (`/harness/depth_camera/*`,
`/wrist_camera/*`) so `profiles/mod101_harness.yaml` — and anything written
against it — is the same file on hardware and in sim. Publishing the RealSense's
native names would fork the profile in two, and the two copies would drift.

One thing does not match sim: the driver stamps images with its **own** optical
frames (`head_camera_color_optical_frame`), not the URDF's
`hn_realsense_optical_frame`. The camera's frames hang off the URDF link
`hn_realsense_1` via `base_frame_id`, so TF resolves — but if you deproject
against the profile on hardware, the head camera's `frame:` has to name the
driver's frame.

Prefer a `/dev/v4l/by-id/...` path for `wrist_camera_device`: `/dev/video0` is
whichever camera enumerated first, which changes when the RealSense is plugged
in.

## Motor IDs

1–5 arm, 6 jaw, 7–8 head. 1–6 are the SO-101 factory order; 7 and 8 are a
convention this package chose.

The IDs in `servos.yaml` are only the **fallback** — what runs before anything
has been calibrated. Once the configurator has written
`servos.generated.yaml`, the IDs and directions come from what actually
answered on the bus, and editing `servos.yaml` will not change them. IDs live in
servo EEPROM; the configurator's Hardware tab both scans for them and reassigns
them.

`require_motors: true` means the driver refuses to start unless all eight
answer. The usual reason they do not is motor power: the logic side is USB-fed,
so the port opens and the chain stays silent, which looks like a working driver
with a dead robot.

## Not done yet

- **Only the `jaws` tool has a hardware path.** `parallel`, `pincopen` and
  `none` still emit `mock_components/GenericSystem` when `use_sim:=false`;
  `tool.ros2control` in each needs the same `$(arg hardware)` block the jaws
  tool now has.
- **The head's motor IDs and directions are unverified** — nothing has been on
  the bus yet.
- **No e-stop.** `brake_method: torque_disable` drops torque when a group is
  commanded to stop, but nothing here cuts power, and a servo holding position
  with a stalled motor draws current until it cooks. The configurator's Disarm
  is the only thing that drops torque on demand, and it needs the bus to itself.

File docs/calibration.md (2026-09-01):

# Calibration

The configurator's **Calibrate** tab (`configurator/calibrate.html`) is the
bring-up path for a physical arm: it sweeps each joint by hand, derives its
travel limits and home position from the motion, verifies the joint is
mechanically healthy, checks that travel against the URDF the arm will actually
be driven by, and then emits the two config files that ROS and LeRobot each need.

The page has two tabs, over one shared bus connection:

Prose on the page itself is kept behind the **(i)** in each panel header — the
explanations are worth having once and in the way every load after that.

- **Hardware** — the serial chain and nothing else. Pick a port, scan the bus,
  and get one card per servo that answers. The servo is the component and the
  card is all of it: its ID, the joint it happens to be mapped to (ROS joint,
  LeRobot motor, sign, model), its live telemetry, and the buttons that move it.
  Reassigning an ID is the one bus-wide action, so it stays outside the cards.
- **Model check** — the same three.js scene as the build page, loaded from
  `configurator/viewer.js`, driven by live servo telemetry. Each joint is swept
  here, the model follows the arm as you move it, and the measured travel is put
  side by side with the joint's URDF `<limit>`.

**Every joint is one servo.** There is no mirrored-pair path.

The wizard flow is ported from the Axon calibration tool in
`link101/link-base101/web/calibrate.html`, but the transport is not: this talks
to the servos **directly**, with no intermediate firmware. The DDSM210 wheel
control that lived alongside the original in `axon-config.html` is deliberately
not carried over — that's base101 chassis hardware, not ST-series servos.

```bash
pip install st3215                 # once
python3 configurator/server.py     # http://localhost:8001/calibrate.html
```

Your user needs read/write on the serial device — on Debian/Ubuntu that means
membership in `dialout` (`sudo usermod -aG dialout $USER`, then log out and
back in).

## How it's wired

```
browser (calibrate.html)
   │  HTTP/JSON
   ▼
configurator/server.py  ──► configurator/motors.py ──► st3215 ──► USB-TTL ──► servo chain
```

The browser never touches a serial port. `motors.py` owns the port and every
servo transaction; the page drives it over plain HTTP. Two consequences worth
knowing:

- **Any browser works.** There's no Web Serial dependency, so Firefox and
  Safari are fine.
- **The bus is serialized.** All access goes through one lock, and the built-in
  HTTP server handles one request at a time. The telemetry poller deliberately
  skips whichever joint is being swept or drive-tested so it isn't competing
  with that joint's own read loop.

`motors.py` is also where `st3215`'s inconsistent return values get flattened —
`ReadSpeed` hands back a `(speed, comm, error)` tuple while its siblings return
a scalar or `None`, `StartServo` returns a tuple where `StopServo` returns a
bool, and `ChangeId` returns `None` on *success* — where "success" only means
the bytes reached the UART, because its EPROM ops are all TxOnly. `change_id()`
therefore pings the new ID to learn what actually happened, refuses an ID that
is already answering, and re-locks the EEPROM (the library's own final
`LockEprom` is addressed to the *old* ID, which has already stopped replying).

### HTTP surface

| Endpoint | Purpose |
|---|---|
| `GET /bus` | connection status + known servo IDs |
| `GET /bus/ports` | candidate serial devices (USB only, unless there are none) |
| `POST /bus/connect` | `{port}` — open and scan |
| `POST /bus/disconnect` | disarm + close |
| `POST /bus/scan` | re-ping IDs 1..99 |
| `POST /bus/disarm` | torque off everything |
| `GET /servo/<id>` | telemetry: pos, speed, current, voltage, load, temp |
| `POST /servo/<id>/torque` | `{on}` |
| `POST /servo/<id>/move` | `{pos, speed?, accel?}` |
| `POST /servo/<id>/profile` | `{speed, accel}` |
| `POST /servo/<id>/zero` | `{target}` — define the current position as `target` (writes EEPROM) |
| `POST /servo/<id>/id` | `{to}` — reassign servo ID (writes EEPROM) |
| `GET /urdf` | the expanded URDF, for the model tab's scene |

Bus scanning is bounded to IDs 1..99 on purpose (`DEFAULT_SCAN_HI`). `st3215`'s
own `ListServos()` pings 0..253, which is seconds of dead time on a real bus.
ID 0 is never scanned, which is why `change_id()` will not assign it.

The arm is left disarmed at every exit: on disconnect, on server shutdown
(`atexit`), and on tab close (the page fires `/bus/disarm` through
`navigator.sendBeacon`, which survives unload).

## The flow

Per joint, in order:

1. **Guided capture** — torque drops and the joint is moved by hand through five
   prompted steps, in this order:

   | step | what you do | what it captures |
   |---|---|---|
   | 1 | put the joint at its **URDF default** | `home` |
   | 2 | move to the **maximum right** stop | one limit |
   | 3 | move to the **maximum left** stop | the other limit |
   | 4 | **sweep twice**, stop to stop | the health check |
   | 5 | return to the **URDF default** | the slip check |

   Limits are the two captured stops with `MARGIN` = 30 ticks pulled in from
   each, so a calibrated limit never commands into the stop itself.

   Steps 1 and 5 — the two that hold the joint at its zero pose — also offer
   **Set zero here** and **Set centre here**; see
   [The encoder seam](#the-encoder-seam).

   **Home is the URDF default, not the middle of the travel**, and it is
   captured first for two reasons. Everything downstream is an angle relative to
   home — ROS radians, LeRobot's `homing_offset`, the pose the 3D model draws —
   so if home were the midpoint of the measured travel then "0 rad" would mean
   "halfway between the stops", which is the URDF's zero only on a joint that
   happens to be symmetric. On every other joint the model and the hardware
   would sit at different angles while both claimed zero. And it has to be step
   1 because the model has nothing to draw against until it exists: before home
   is known the anchor is wherever the arm was when first seen.

   Step 4 needs two full end-to-end traversals; the counter watches for arrival
   at one captured end having last been at the other, so a twitch at the top of
   the range does not score as a sweep. Step 5 is the one that catches an
   encoder that moved during those sweeps — the joint is returned to the same
   physical pose, so any residual is slip, and every limit just measured is off
   by that much. Under 8 ticks reads as servo noise; more is reported as a
   fault.
2. **Verdict** — `clean` or `fault`. A joint fails on a position discontinuity
   (`JUMP_THRESH` = 400 ticks ⇒ encoder slip).
3. **Accept** — adjust min/max/home, or capture each from the current
   hand-held position. The page shows live what those ticks mean in radians for
   the mapped ROS joint, and how that compares to the joint's URDF `<limit>`.
4. **Arm-check** — re-arms at a slow profile holding present position, then
   reads current. Must be low (< 250 mA) or it disarms immediately. This is a
   *soft* check: nothing in this path can cap current in hardware.
5. **Drive test** — jog the joint across its calibrated range under power and
   watch the tracking error, with the model tracking it pose for pose.

### What a write produces

| file | for |
|---|---|
| `src/mod101_control/config/calibration.yaml` | ROS — radians relative to each joint's home |
| `src/hardware/mod101_hw_bringup/config/servos.generated.yaml` | the hardware servo driver — motor IDs, joints, directions |
| LeRobot calibration JSON | LeRobot |

The middle one is what makes calibrate-then-launch enough to get a working arm.
It carries the **wiring** half of the servo driver's config — which motor ID is
which joint and which way it turns, straight out of the servo map on the
hardware tab. The bus port, rates, speeds and group structure stay hand-authored
in `servos.yaml`, which the configurator never overwrites, and
`bringup.launch.py` merges the two before injecting the tick calibration from
the first file. See
[mod101_hw_bringup](../src/hardware/mod101_hw_bringup/README.md).

Group membership is read out of `servos.yaml` rather than guessed from joint
names. A servo mapped to a joint that no group claims — or a group joint with no
servo behind it — is reported in the console after the write.

**Start over** (in the *Joints* panel header) discards every calibrated value
and runs the wizard again from the first joint: results, model anchors and the
working min/max/home are cleared, and anything still armed is disarmed — a
drive-test leaves its joint under power, and its Disarm button goes away with
the card that owned it.

It deliberately **keeps the servo map**. Joint names, signs, LeRobot names and
models describe how the bus is wired, not what a sweep found; re-typing them
after every restart is how a sign ends up wrong, and a wrong sign is the failure
that survives all the way to a policy driving the arm backwards. Use
Export/Import on the hardware tab to move a map between machines.

**Nothing is written to the servos.** Calibration lives in the generated repo
files, not in servo EEPROM — no wear, and nothing lost when a servo is swapped.
The only EEPROM write in the whole page is the explicit *Reassign a servo ID*
action.

### The encoder seam

The encoder is absolute over one turn and its count wraps 4095 → 0 at one
physical angle, decided by nothing more than how the horn happened to spline on.
If that seam falls inside a joint's travel, the calibrated range is an arc
across it and **`ticks_min` comes out numerically larger than `ticks_max`**.

The page itself does not care — everything here is computed as signed ticks from
home, and `wrapSigned` keeps such an arc contiguous. The *files* care, because
`ticks_min`/`ticks_max` and LeRobot's `range_min`/`range_max` are plain numbers
with no seam in them. `st3215_manager`'s `MotorGroup` rejects the group outright
(`min_ticks >= max_ticks`) and the driver refuses to start — at launch, on
another day, a long way from the arm the numbers were measured on.

**Set zero here** and **Set centre here**, on either of the guided flow's
zero-pose steps, each write a position-correction offset into the servo's EEPROM
so that the pose being held reads a chosen tick. That survives power cycles and
the ROS driver reads the same shifted frame, which is the point — a fix that
lived only in this page would be undone by the next power-up. The ticks already
captured for that joint are rebased by the same shift, so the flow carries on
rather than starting again, and other joints are untouched.

**There are two buttons because there are two shapes of joint, and it is a fact
about the mechanism rather than about the numbers.**

| | for | target | why |
|---|---|---|---|
| **Centre** | the zero pose is in the **middle** of the travel and the joint moves both ways from it | 2048 | half the encoder available in each direction |
| **Zero** | the zero pose **is a hard stop** and the joint moves one way only | 250, or 3845 if the travel runs the other way | the whole range goes to the side that can use it, and nothing can drive past the stop into the seam |

Centring a one-sided joint spends half the encoder on a direction it cannot
travel, and on a joint with 180° of range that puts the far end past 4095 — it
manufactures the seam crossing it was reached for. mod101 splits four and four:

| joint | range | zero pose is | button | travel |
|---|---|---|---|---|
| `joint_base` | −90° … 90° | mid-travel | centre → 2048 | 1024 … 3072 |
| `hn_pan_joint` | −90° … 90° | mid-travel | centre → 2048 | 1024 … 3072 |
| `hn_tilt_joint` | −80° … 80° | mid-travel | centre → 2048 | 1138 … 2958 |
| `joint_wrist_tilt` | −70.5° … 88.2° | mid-travel | centre → 2048 | 1246 … 3052 |
| `joint_shoulder` | −0.1° … 180° | a hard stop | zero → 250 | 249 … 2298 |
| `joint_elbow` | −0.1° … 180° | a hard stop | zero → 250 | 249 … 2298 |
| `joint_wrist_roll` | 0° … 180° | a hard stop | zero → 250 | 250 … 2298 |
| `6` (jaw) | 0° … 122.6° | a hard stop | zero → 250 | 250 … 1645 |

The page reads the URDF's range and marks the button it suggests, but **the
suggestion does not gate anything**. Whether the default pose is really a hard
stop is something you can feel and the URDF cannot, and a placement whose
declared travel would not fit is a warning in the log, not a refusal — an arm
whose URDF is wrong is precisely what this page exists to find, so it must stay
calibratable.

`ZERO_MARGIN` is 250 ticks (~22°) rather than 0. The stop is a stop, but the
pose is set against it **by hand**, and the URDF's idea of the default may
itself sit a degree or two off it — a joint zeroed 22° adrift still does not
wrap. On the widest joint here that still leaves ~1800 ticks unused, so the
margin costs nothing that is needed.

**When to press one.** At step 1, joint held at its URDF default, before
capturing — once per servo, the first time that arm is calibrated. The offset is
in EEPROM, so it is not a per-calibration step; a later recalibration inherits
it. Press again only when the mechanics change (horn re-splined, servo swapped,
joint reassembled), and necessarily when a verdict shows the seam banner,
because nothing else clears that. Pressing the right one on a joint that does
not need it is harmless. The one reason to hold off is an existing LeRobot
calibration worth keeping: this shifts the frame it was measured in.

The pose it is pressed at is the pose that becomes the reference, so a joint
held 20° off its default puts the whole travel 20° off. That costs margin rather
than correctness, but it is not a button to press with the joint somewhere
arbitrary.

This is also why the buttons are only on steps 1 and 5: both targets are
measured from the zero pose, so pressing either at a hard stop would place the
range from the wrong reference.

Three things guard the failure independently: the flag on the guided result, a
live banner under the editable limits that disables **Accept**, and a refusal in
`bakeJoint` — the one funnel every path takes, including manual entry.

Two caveats. The servo must be **disarmed**: re-framing one that is holding
position leaves its goal register meaning a different angle, and it slews there
the moment the offset lands, so the request is refused if torque is on. And this
is the page's only write to servo EEPROM besides ID assignment; calibration
itself deliberately stays in the repo's generated files.

## The servo card

Everything true of one servo is on one card, because on the bench it is one
question: *which motor is this, is it answering, what joint does the map think
it is, and what happens when I move it?* That used to be a mapping table, a
separate **Drive a servo** pane and a **Joint status** sidebar — three places to
watch while turning one motor, and only one of the three said which joint the
motor even was.

The cards stack one per row, and each splits the way the work does: **everything
you set on the left, everything the servo tells you on the right.** Left is the
four mapping fields, the drive row and the speed/accel fold; right is eight live
readings — position, angle, velocity, goal, current, voltage, load, temperature.
A header spanning both carries the online dot, the ID, the mapped joint name and
the torque state. Clicking a card selects it, which is also what the model tab
highlights. Below 1080px the two halves stack instead.

### Jogging

**Torque on** arms the servo at its present position, so arming never makes it
snap anywhere. Only then do **−** and **+** light up: an STS servo ignores a goal
it isn't armed for, and buttons that look live while doing nothing are worse than
buttons that are visibly off.

Each press commands exactly one step — 1, 5, 10 or 25 ticks (0.1° to 2.2°),
picked from the step selector, which is shared across every card. **Nothing
repeats while a button is held**, and the next press waits for the current one to
be acknowledged. This replaced a 0…4095 slider: the slider spanned the raw
encoder range rather than any calibrated travel, so a single drag could take a
joint into its hard stop. Steps still add up — watch the joint, and keep
**Disarm all** in reach.

Where the step counts from depends on whether the servo is holding. Armed, it is
still chasing its last goal, so the step is added to that goal — counting from
the present position would land inside the motion already in flight and every
press would ask for less than a step. Unarmed, the joint can be moved by hand,
which makes the tracked goal stale, so the step is added to a fresh reading.

Goals are **clamped** at 0 and 4095 rather than wrapped. Those are the ends of
the encoder, and a button that silently jumped a joint half a turn across the
0/4095 seam would be the most dangerous control on the page.

## Joint mapping

There's no configuration stored on the arm, so the cards' mapping fields are the
only source of truth for which servo is which joint. Defaults follow
`mod101_description/urdf/mod101_macro.xacro`:

| ID | ROS joint | LeRobot | Sign |
|---|---|---|---|
| 1 | `joint_base` | `shoulder_pan` | +1 |
| 2 | `joint_shoulder` | `shoulder_lift` | **−1** |
| 3 | `joint_elbow` | `elbow_flex` | +1 |
| 4 | `joint_wrist_tilt` | `wrist_flex` | **−1** |
| 5 | `joint_wrist_roll` | `wrist_roll` | +1 |
| 6 | `6` (tool joint) | `gripper` | +1 |
| 7 | `hn_pan_joint` | — | +1 |
| 8 | `hn_tilt_joint` | — | +1 |

**Sign** reconciles the servo's counting direction with the URDF joint axis.
`joint_wrist_tilt` has axis `0 -1 0`, hence −1 by default. `joint_shoulder`'s
axis is `0 1 0` and positive does lift the arm, but the servo on this build
counts the other way, so it is −1 too — measured, not derived. The tool joint
is literally named `6` per [tool-convention.md](tool-convention.md).

**7 and 8 are the camera tower**, not the arm, so they have no LeRobot
counterpart — the export keys them `head_pan` / `head_tilt` only to keep the
JSON unique. Their travel is **declared, not swept**: the pan/tilt was driven to
its URDF zero and given ±90° (1024 ticks) each way by decision, because the
mechanism has no hard stop to sweep into within that range. That makes
`ticks_min`/`ticks_max` a policy limit rather than a measured one — if the head
does foul something before 90°, the driver will happily drive into it instead
of clamping short. Re-sweep them here to replace the declared numbers with real
ones. Neither arc crosses the 0/4095 seam, but servo 8's max lands at 4068, 27
ticks short of it; moving the tilt zero up would push the arc over.

**ROS joint** is a picker over the joints the loaded URDF actually declares,
not free text — a typo there is a joint that silently never matches the model,
which is exactly what the model tab exists to catch. Press **Rebuild joints**
after renaming.

Edits persist in `localStorage` and travel with the exported JSON.

Getting a sign wrong is the classic failure: sim and hardware move opposite
ways on that one joint. Check each against the URDF before trusting a policy.

## Model check — does the URDF fit the arm?

The model tab answers one question: for every joint, does the URDF's declared
travel match what the hardware actually has?

The scene is the build page's, imported from `configurator/viewer.js` so there is
one renderer, one URDF fetch and one Z-up correction rather than two that drift.
On top of that the calibration page adds:

- **Live pose from the bus.** Every telemetry read is converted to an angle and
  pushed at the model, so the arm and the model move together. A servo tick only
  becomes an angle once you know which tick is the joint's zero — before a joint
  is calibrated the anchor is wherever the arm was when first seen, and from the
  moment step 1 of the guided flow captures the URDF default it is that tick,
  held for the rest of the flow. Nothing re-anchors mid-sweep, so the joint on
  screen tracks the hardware instead of drifting as the measured range grows.
- **Limits deliberately not enforced.** `setIgnoreLimits(true)` — a joint driven
  past what the URDF declares has to be visible, because that mismatch is the
  thing being looked for.
- **Highlight.** The link a joint drives directly lights up. With *follow motion*
  ticked, whichever joint is actually turning takes the highlight, so nudging a
  joint by hand tells you which one the map thinks it is.
- **Travel bars.** Two bands on one scale — what the URDF declares, and what was
  measured — with a live needle. Where the URDF reaches past the measured travel,
  the band goes red.

The **URDF ↔ hardware fit** table scores each joint, within a 2° tolerance:

| verdict | meaning |
|---|---|
| `1:1` | measured travel matches the `<limit>` both ends |
| `conservative` | the arm has more travel than the URDF allows — safe, just unused |
| `over-travel` | **the URDF allows more than the arm has** — a planner will command into a hard stop |
| `not in urdf` | a servo mapped to a joint the URDF doesn't declare |
| `no servo mapped` | a URDF joint with no servo behind it |

`over-travel` is the failure; the other direction only wastes reach. **URDF limit
block** prints the measured ranges as paste-ready `<limit>` lines. Nothing on
this page writes the URDF — the build page owns that file.

## Output

**Write to repo** posts to `POST /calibration`, which writes both files into
`src/mod101_control/config/` (already covered by the package's
`install(DIRECTORY config ...)`):

- **`calibration.yaml`** — ROS. Per joint: servo ID, model, sign, the raw tick
  min/max/home, and `limit_lower`/`limit_upper` in radians relative to home.
- **`lerobot_calibration.json`** — LeRobot. Per motor: `id`, `drive_mode`,
  `homing_offset`, `range_min`, `range_max`.

Both are **generated files**. Re-run the wizard rather than hand-editing them.

### The tick math

STS3215 encoders are 4096 counts/rev and direct-drive, so one tick is
`2π/4096` rad and the same counts serve both stacks:

```
ROS:      limit = sign · wrapSigned(ticks − home) · 2π/4096
LeRobot:  homing_offset = 2047 − home
          range_min/max = min/max + homing_offset
          drive_mode    = 1 when sign is −1
```

`wrapSigned` keeps an arc that crosses the 0/4095 seam contiguous instead of
spiking. All of this is covered by the page's **Self-test** button, which runs
29 assertions over synthetic sweeps — including the seam case, both signs, the
URDF fit verdicts, the guided flow's captures (home is the captured default
rather than mid-travel, limits pull `MARGIN` in from both stops, captures either
side of the seam, and the return-to-default residual), and both placements:
which one each shape of joint is told to use, that zero follows the travel to
whichever end of the count it runs toward, and that each placement fits its own
shape while the *other* one overruns 0..4095 — the regression the two buttons
exist for. No hardware attached.

The seam is where this stops being arithmetic: `wrapSigned` handles it here, and
the generated files cannot express it at all. See
[The encoder seam](#the-encoder-seam).

> **Verify the LeRobot schema against your installed version.** The calibration
> file's field names have moved between LeRobot releases. The shape written
> here matches the SO-101 follower layout; confirm before relying on it.
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

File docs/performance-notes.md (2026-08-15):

# Performance notes and DDS traps

Measurements from 2026-08-13, taken while bringing up MoveIt on an i9-13900K
under WSL2. Written down because most of the "this feels slow" and "this is
flaky" in this stack turned out **not** to be what it looked like.

Headline: **the hardware and WSL are not the bottleneck.** Bringup is dominated
by fixed `sleep`s in the launch files, and most intermittent failures are DDS
environment problems, not code.

---

## What was measured

| Thing | Result | Verdict |
|---|---|---|
| Gazebo real-time factor | **0.992** (7.64 s sim in 7.70 s wall, GUI running) | Real time. Physics is fine. |
| GPU | `/dev/dxg` present, no llvmpipe, OpenGL 4.5 | Hardware accelerated |
| Filesystem | `/home/cdr` = ext4 | Native. (`/mnt/c` **would** be slow) |
| move_group robot-model parse | 0.002 s | Free |
| OMPL plan (home → ready) | 0.07–0.26 s | Fast |
| IK (pick_ik, 5-DOF) | 0.07–0.21 mm error, well inside its 50 ms budget | Fast |
| CPU / RAM | 32 threads, 31 GB | Idle during startup |
| Collision geometry | 16 meshes, **111,766 triangles**, visual == collision | Coping, but see below |

Gazebo throttles to real time by design, so a 3-second trajectory takes 3
seconds. That's not slowness.

### How to re-measure RTF

```python
# rtf.py — run against a live sim
import time, rclpy
from rclpy.node import Node
from rosgraph_msgs.msg import Clock
from rclpy.qos import QoSProfile, ReliabilityPolicy, DurabilityPolicy, HistoryPolicy
rclpy.init(); n = Node('rtf')
qos = QoSProfile(depth=10, reliability=ReliabilityPolicy.BEST_EFFORT,
                 durability=DurabilityPolicy.VOLATILE, history=HistoryPolicy.KEEP_LAST)
s = []
n.create_subscription(Clock, '/clock', lambda m: s.append(
    (time.time(), m.clock.sec + m.clock.nanosec * 1e-9)), qos)
end = time.time() + 12
while time.time() < end:
    rclpy.spin_once(n, timeout_sec=0.2)
(w0, t0), (w1, t1) = s[0], s[-1]
print(f'RTF = {(t1 - t0) / (w1 - w0):.3f}')
```

## Where bringup time actually goes

`demo.launch.py` reaches "You can start planning now!" in roughly 16–20 s, and
**almost all of it is hardcoded `TimerAction` delays**, not work:

| Stage | Source | Delay |
|---|---|---|
| joint_state_broadcaster | `gazebo.launch.py` | 3 s |
| arm_controller | `gazebo.launch.py` | 5 s |
| tool gripper_controller | `mod101_tool_*/launch/tool.launch.py` | 10 s |
| arm/gripper trajectory controllers | `demo.launch.py` | 8 s, 10 s |
| move_group | `demo.launch.py` | 16 s |

Measured stage completion in Gazebo: JSB at +2.5 s, arm JTC at +5.3 s, gripper
JTC at +7.5 s, robot model loaded at +13.0 s. The CPU is idle through most of
that. A faster machine does **not** help — the timers are wall-clock.

### The event-driven fix — attempted, and it FAILED

The obvious improvement is to drop the timers: the `spawner` blocks on
`/controller_manager`'s services by itself, so it can start immediately, and
subsequent spawners can chain off `RegisterEventHandler(OnProcessExit(...))`.

**This was implemented and it broke bringup.** Do not retry it blind.

Symptom, in `mock.launch.py`: starting a spawner in the same instant as
`ros2_control_node` makes the controller manager **never receive
`/robot_description`**. It hangs forever printing:

```
[controller_manager]: Waiting for data on 'robot_description' topic to finish initialization
```

In `demo.launch.py` the same change produced a sibling failure — `ros_gz_sim
create` couldn't fetch the description either:

```
[ros_gz_sim]: Failed to get XML from topic [robot_description]
```

Reproduced 3/3 with a freshly cleaned `/dev/shm`, so it is **not** shm
contamination. Relevant facts:

- `controller_manager` 4.45 **ignores a `robot_description` parameter** — it
  only reads the `/robot_description` topic, which `robot_state_publisher`
  latches (transient_local).
- Delaying `ros2_control_node` instead of the spawner does **not** help
  (tested: still 0/3).
- Delay sensitivity on the spawner was non-monotonic — 0.5 s worked, 1.0 s and
  2.0 s failed, 3.0 s worked. That erraticism is unexplained and is the reason
  this wasn't just tuned to a smaller number.

Everything was **reverted to the original timers**, which are verified working.
The delays now carry comments pointing here.

If you pick this up again: the mechanism to understand first is why a
late-joining subscriber misses a latched `robot_description`, and why a third
participant appearing seems to trigger delivery. `OnProcessIO` watching for
`"Received robot description from topic."` before starting spawners is a
plausible event-driven approach that avoids guessing.

## DDS traps

Two separate environment problems, both of which produce failures that look
exactly like code bugs. Between them they cost hours.
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

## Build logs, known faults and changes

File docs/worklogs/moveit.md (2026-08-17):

# MoveIt 2 — handover

> **ARCHIVED WORKLOG — 2026-08.** This was the handover note written when
> MoveIt support landed. It is kept for the reasoning and the measurements, not
> as current documentation: several items here have since been resolved, and the
> collision-matrix numbers predate `rigid_adjacency()`.
>
> **For current documentation see [../moveit.md](../moveit.md).**

State of the MoveIt work as of 2026-08-13. What exists, what's proven, what
isn't, and what I'd do next.

Nothing here is committed — it's all in the working tree.

Companion docs: [moveit-getting-started.md](../moveit-getting-started.md) (the
walkthrough), [moveit.md](../moveit.md) (the reference),
[performance-notes.md](../performance-notes.md) (why bringup feels slow, and the
DDS traps).

---

## What was added

**New package `mod101_moveit_config`**

```
srdf/mod101.srdf.xacro            parametric SRDF (takes `tool`, like the URDF)
config/kinematics.yaml            pick_ik, position-only  <- the important one
config/joint_limits.yaml          velocity/accel for time parameterisation
config/ompl_planning.yaml         RRTConnect default
config/moveit_controllers.yaml    arm's FollowJointTrajectory handle
config/collisions/<tool>.srdf.xacro   GENERATED self-collision matrices
config/moveit.rviz                MotionPlanning panel config
launch/demo.launch.py             Gazebo + move_group + RViz
launch/mock.launch.py             mock hardware, no Gazebo, headless-friendly
launch/move_group.launch.py       move_group alone (attaches to a running CM)
test/moveit_smoke.py              FK/IK/plan/execute checks, non-zero on failure
examples/move_to_position.py      "move the tip to x y z" reference script
```

**New `tools/gen_collision_matrix.py`** — regenerates the collision matrices.

**Each `mod101_tool_*` gained** `srdf/tool.srdf.xacro` (its planning group + end
effector) and `config/moveit_controllers.yaml`, plus a
`gripper_trajectory_controller` in its `controllers.yaml`. The one-package-per-
tool contract is preserved; `docs/ros-architecture.md` documents the new files.

**Modified outside the new package**

| File | Change |
|---|---|
| `mod101_gazebo/launch/gazebo.launch.py` | new `spawn_controllers` arg (default true) |
| `mod101_gazebo/config/gz_ros_bridge.yaml` | **removed duplicate `/clock` bridge** — see below |
| `mod101_control/urdf/mod101.hardware.xacro` | robot name `mod101_hardware` → `mod101` (MoveIt requires URDF and SRDF names to match) |
| `mod101_control/config/controllers.sim.yaml` | corrected the stale JTC-segfault comment |
| `mod101_tool_*/launch/tool.launch.py` | accept `spawn_controllers` |

## Verification status

`test/moveit_smoke.py` checks FK on `ready` → IK back to that pose → IK
correctly *failing* on an unreachable pose → an OMPL joint-space plan →
execution through ros2_control.

| Bringup | Tools | Result |
|---|---|---|
| `mock.launch.py` | jaws, parallel, pincopen, none | **5/5 each** |
| `demo.launch.py` (Gazebo) | jaws | **5/5** |

Also verified: all four SRDFs expand; `pick_ik` solves the 5-DOF chain to
0.07–0.21 mm; planning takes 0.07–0.26 s; Gazebo runs at **RTF 0.992**;
`examples/move_to_position.py` plans, executes, and fails correctly out of range.

**Not verified: anything visual.** I could never see RViz — WSLg composites
through Wayland, so an X root-window grab returns black, and there's no
`Xvfb`/`grim`/`xdotool` installed. `config/moveit.rviz` is correct as far as
RViz's logs go (plugins load, interactive-marker server connects, no parse
errors) but nobody has confirmed the panel *looks* right. In particular the
config carries no `QMainWindow State` blob, so panel docking falls back to
RViz's defaults; if it lands badly, arrange it and **File → Save Config As**
over `config/moveit.rviz`.

## The two decisions that matter

### 1. 5 DOF → position-only IK

Joints are base yaw (Z), then shoulder/elbow/wrist-tilt — **all pitch about
parallel ±Y** — then wrist roll (X). The tool's azimuth is rigidly tied to
`joint_base`, so arbitrary 6-DOF poses are unreachable.

MoveIt's default KDL solver needs ≥6 DOF and fails on essentially every goal,
which reads as a broken install. So `kinematics.yaml` uses **`pick_ik` with
`rotation_scale: 0.0`**. Consequence for all downstream code: **plan to
positions, not poses.** `ros-jazzy-pick-ik` is a hard dependency.

### 2. Controllers: don't spawn-then-switch

`arm_controller`/`gripper_controller` (position) and the trajectory controllers
claim the same joints, and controller_manager permits one active claim per
joint. The first implementation spawned the position controllers then switched
away; that races the spawner and `ros2 control switch_controllers` hangs when
it loses. Now the MoveIt launches pass `spawn_controllers:=false` and bring up
only the trajectory controllers. The plain Gazebo launch is unchanged by
default (re-verified).

## The collision-matrix question — measured

The matrices are generated, not hand-written, because rail lengths and the
`small|big` mount swap move geometry. I measured how much they actually change
across the configurator's full 80–280 mm range (tool=jaws):

These counts are a **historical measurement**, taken at 10,000 trials and before
`rigid_adjacency()` existed. Today the same default build reports 167 pairs at
1,000,000 trials. The *shape* of the result below still holds — that is what the
section is for — but do not compare the absolute numbers against a current file.

| Config | pairs | extra vs default | **missing vs default** |
|---|---|---|---|
| short + small (default) | 122 | — | — |
| long + small | 133 | 11 | **0** |
| short + **big** | 114 | 0 | **8** |
| long + **big** | 129 | 11 | **4** |

**Rail length is harmless** — lengthening only ever *adds* disabled pairs, so
the default matrix on a long arm is conservative: slightly slower, never wrong.
Moving the length sliders does **not** require regeneration.

**The `small` → `big` mount swap is dangerous.** It removes 8 pairs that the
larger servos genuinely bring into contact (`arm_extrusion_1`↔`servo_shoulder_1`,
`elbow_adapter_1`↔`elbow_link_1`, `camera_wing_1`↔`elbow_link_1`, …). Shipping
the small-mount matrix on a big-mount build silently blinds the planner to
those.

**Resolved — the alternative won.** The generator is wired into the
configurator's Save: `regen_collisions_async()` runs it in a background thread
with a 900 s timeout, and `GET /collisions` reports status. Shipping an
intersection was not needed.

Three caveats worth carrying forward:

- **It regenerates mod101 and nothing else.** An earlier version reached into a
  base101 workspace via a `BASE101_WS` setting. That inverted the dependency —
  the arm had to know where its consumers lived, which breaks with two of them,
  or one on another machine, or a consumer that isn't base101. Consumers now own
  their own regeneration; the Save response carries a `downstream` note naming
  the script to run. For base101 that is
  `base101_arm_moveit_config/scripts/sync_arm_change.sh`.
- **A green Save is not proof.** Regeneration reports
  `skipped: workspace not built` and carries on. Check `GET /collisions`.
- **The 8 "missing" pairs above were two different problems.** Some were genuine
  build-dependence, which regenerate-on-save fixes. But
  `elbow_adapter_1`↔`elbow_link_1` was never a sampling question at all: those
  are the two halves of the elbow hinge, one link apart across a *fixed* joint,
  so `collisions_updater` can never mark them `Adjacent` and they always collide
  when sampled. They fell through both nets on every build. `rigid_adjacency()`
  in the generator now emits that class of pair from the joint graph directly.

Nothing else is a precomputed artifact — URDF and SRDF are both xacro, expanded
at launch. And `colcon build --symlink-install` means config edits need no
rebuild.

## Open items

**Should do**

1. ~~**Collision matrix strategy**~~ — **resolved.** Regenerate-on-save won:
   `configurator/server.py` calls `regen_collisions_async()` on every Save. It
   regenerates **mod101 only** — consumers own their own matrices and the Save
   response carries a `downstream` note telling you to run theirs. The specific
   pair this section worried about, `elbow_adapter_1`↔`elbow_link_1`, is now
   emitted structurally by `rigid_adjacency()` rather than left to sampling.
2. **Verify RViz visually** — first thing worth doing on native Linux.
3. **Joint dynamics are still estimates.** `config/joint_limits.yaml` holds
   conservative guesses and the URDF's `velocity="100"` is placeholder CAD data.
   Joint *travel* is no longer an estimate: the wrists are bounded `revolute`
   (tilt −1.23 … 1.54, roll 0 … π) and the shoulder/elbow stops carry a −0.001
   margin.

**Nice to have**

4. **Collision meshes are the full-res visual STLs** — 16 meshes, 111,766
   triangles, same geometry for visual and collision. Planning is fine, but
   convex hulls would cut collision-checking cost and help Gazebo.
5. **The tool joint is named `6`.** Legal, but needs quoting in every YAML and
   reads badly in SRDF. `joint_gripper` would touch all four tool packages.
6. **Bringup takes ~16 s of fixed timers.** See
   [performance-notes.md](../performance-notes.md) — there's a failed experiment
   documented there; read it before retrying.

**Known upstream, not ours**

- `move_group` segfaults in `~TrajectoryExecutionManager` on Ctrl-C (MoveIt
  2.12 / rclcpp teardown). Happens after everything has stopped.
- `/recognize_objects not available` on startup — stock MoveIt, harmless.

## Gotcha worth knowing before debugging anything

Intermittent "controller failed to load", "Waiting for data on
`robot_description`", or `CONTROL_FAILED` are usually **environment, not code** —
stale FastDDS shared-memory segments, or another ROS system on your DDS domain.
Both cost me hours. See [performance-notes.md](../performance-notes.md#dds-traps).

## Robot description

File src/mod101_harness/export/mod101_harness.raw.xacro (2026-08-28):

<?xml version="1.0" ?>
<robot name="mod101_harness" xmlns:xacro="http://www.ros.org/wiki/xacro">

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
<xacro:include filename="$(find mod101_harness)/export/materials.xacro" />
<xacro:include filename="$(find mod101_harness)/export/mod101_harness.raw.ros2control" />
<xacro:include filename="$(find mod101_harness)/export/mod101_harness.raw.gazebo" />
<link name="base_link">
  <inertial>
    <origin xyz="0.7183668847290359 -0.1898371852815478 -0.018503159635172448" rpy="0 0 0"/>
    <mass value="0.4359046662837625"/>
    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
  </inertial>
  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
</link>

<link name="yaw_bracket_1">
  <inertial>
    <origin xyz="-0.24048767950999106 0.02833424258398279 -0.10053283234598204" rpy="0 0 0"/>
    <mass value="0.01768001501876205"/>
    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
  </inertial>
  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
</link>

<link name="yaw_servo_1">
  <inertial>
    <origin xyz="-0.01626256682350069 -0.010250178675302313 -0.015852716380520993" rpy="0 0 0"/>
    <mass value="0.2781207151088369"/>
    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
  </inertial>
  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
</link>

<link name="yaw_mount_1">
  <inertial>
    <origin xyz="-0.0008752813552826977 3.643010852427686e-07 0.002835565808725571" rpy="0 0 0"/>
    <mass value="0.01768001501876205"/>
    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
  </inertial>
  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
</link>

<link name="pitch_servo_1">
  <inertial>
    <origin xyz="0.015852602679255368 -0.010250214439629785 0.016262453122235343" rpy="0 0 0"/>
    <mass value="0.2781207151088369"/>
    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
  </inertial>
  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
</link>

<link name="pitch_link__1">
  <inertial>
    <origin xyz="-0.018217940621004014 -0.00292124752604056 0.018998095012473626" rpy="0 0 0"/>
    <mass value="0.14731389111767698"/>
    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
  </inertial>
  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
</link>

<link name="realsense_1">
  <inertial>
    <origin xyz="-0.021091708113011975 -0.011657624516847098 -2.35569412897485e-05" rpy="0 0 0"/>
    <mass value="0.0720014321602746"/>
    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
  </inertial>
  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
</link>

<link name="mod_101_adapter_1">
  <inertial>
    <origin xyz="0.3290322101958174 -0.013258210571603646 0.07482693375623085" rpy="0 0 0"/>
    <mass value="0.5806071982549674"/>
    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
  </inertial>
  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
</link>

<link name="mod_101_base_1">
  <inertial>
    <origin xyz="-0.03163848079424014 0.02870220773748383 0.009896401508084707" rpy="0 0 0"/>
    <mass value="0.8668211242819504"/>
    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
  </inertial>
  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
</link>

<link name="tower_1">
  <inertial>
    <origin xyz="0.010000022826068933 0.009999792166619115 0.15999970226778837" rpy="0 0 0"/>
    <mass value="0.4359046662837625"/>
    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
  </inertial>
  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
</link>

<link name="back_1">
  <inertial>
    <origin xyz="-0.2932579855783596 -0.44833419350146253 0.07234785241212485" rpy="0 0 0"/>
    <mass value="0.2451971061160035"/>
    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
  </inertial>
  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
</link>

<joint name="Rigid 12" type="fixed">
  <origin xyz="0.237652 -0.018335 0.403258" rpy="0 0 0"/>
  <parent link="tower_1"/>
  <child link="yaw_bracket_1"/>
</joint>

<joint name="Rigid 17" type="fixed">
  <origin xyz="-0.250902 0.038585 -0.085258" rpy="0 0 0"/>
  <parent link="yaw_bracket_1"/>
  <child link="yaw_servo_1"/>
</joint>

<joint name="Revolute 18" type="continuous">
  <origin xyz="-0.029 -0.01025 0.0032" rpy="0 0 0"/>
  <parent link="yaw_servo_1"/>
  <child link="yaw_mount_1"/>
  <axis xyz="0.0 -0.0 1.0"/>
</joint>

<joint name="Rigid 19" type="fixed">
  <origin xyz="-0.01615 0.01025 0.01325" rpy="0 0 0"/>
  <parent link="yaw_mount_1"/>
  <child link="pitch_servo_1"/>
</joint>

<joint name="Revolute 20" type="continuous">
  <origin xyz="0.03405 -0.01025 0.029" rpy="0 0 0"/>
  <parent link="pitch_servo_1"/>
  <child link="pitch_link__1"/>
  <axis xyz="-1.0 0.0 -0.0"/>
</joint>

<joint name="Rigid 21" type="fixed">
  <origin xyz="0.0043 -0.0105 0.032396" rpy="0 0 0"/>
  <parent link="pitch_link__1"/>
  <child link="realsense_1"/>
</joint>

<joint name="Rigid 28" type="fixed">
  <origin xyz="-0.621592 -0.475076 0.0" rpy="0 0 0"/>
  <parent link="back_1"/>
  <child link="mod_101_adapter_1"/>
</joint>

<joint name="Rigid 29" type="fixed">
  <origin xyz="0.357784 -0.033258 0.085748" rpy="0 0 0"/>
  <parent link="mod_101_adapter_1"/>
  <child link="mod_101_base_1"/>
</joint>

<joint name="Rigid 30" type="fixed">
  <origin xyz="0.878367 -0.199837 -0.028503" rpy="0 0 0"/>
  <parent link="base_link"/>
  <child link="tower_1"/>
</joint>

<joint name="Rigid 31" type="fixed">
  <origin xyz="0.941625 0.158497 -0.090851" rpy="0 0 0"/>
  <parent link="base_link"/>
  <child link="back_1"/>
</joint>

</robot>

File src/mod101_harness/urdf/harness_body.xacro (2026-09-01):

<?xml version="1.0" ?>
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
<robot xmlns:xacro="http://www.ros.org/wiki/xacro">

<xacro:macro name="harness_body" params="prefix:=''">

<link name="${prefix}base_link">
  <inertial>
    <origin xyz="0.7183668847290359 -0.1898371852815478 -0.018503159635172448" rpy="0 0 0"/>
    <mass value="0.4359046662837625"/>
    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
  </inertial>
  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
</link>

<link name="${prefix}yaw_bracket_1">
  <inertial>
    <origin xyz="-0.24048767950999106 0.02833424258398279 -0.10053283234598204" rpy="0 0 0"/>
    <mass value="0.01768001501876205"/>
    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
  </inertial>
  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
</link>

<link name="${prefix}yaw_servo_1">
  <inertial>
    <origin xyz="-0.01626256682350069 -0.010250178675302313 -0.015852716380520993" rpy="0 0 0"/>
    <mass value="0.2781207151088369"/>
    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
  </inertial>
  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
</link>

<link name="${prefix}yaw_mount_1">
  <inertial>
    <origin xyz="-0.0008752813552826977 3.643010852427686e-07 0.002835565808725571" rpy="0 0 0"/>
    <mass value="0.01768001501876205"/>
    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
  </inertial>
  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
</link>

<link name="${prefix}pitch_servo_1">
  <inertial>
    <origin xyz="0.015852602679255368 -0.010250214439629785 0.016262453122235343" rpy="0 0 0"/>
    <mass value="0.2781207151088369"/>
    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
  </inertial>
  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
</link>

<link name="${prefix}pitch_link__1">
  <inertial>
    <origin xyz="-0.018217940621004014 -0.00292124752604056 0.018998095012473626" rpy="0 0 0"/>
    <mass value="0.14731389111767698"/>
    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
  </inertial>
  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
</link>

<link name="${prefix}realsense_1">
  <inertial>
    <origin xyz="-0.021091708113011975 -0.011657624516847098 -2.35569412897485e-05" rpy="0 0 0"/>
    <mass value="0.0720014321602746"/>
    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
  </inertial>
  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
</link>

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
<link name="${prefix}realsense_optical_frame"/>
<joint name="${prefix}realsense_optical_joint" type="fixed">
  <origin xyz="0 0 0" rpy="-1.570796 0 3.141593"/>
  <parent link="${prefix}realsense_1"/>
  <child link="${prefix}realsense_optical_frame"/>
</joint>

<link name="${prefix}mod_101_adapter_1">
  <inertial>
    <origin xyz="0.3290322101958174 -0.013258210571603646 0.07482693375623085" rpy="0 0 0"/>
    <mass value="0.5806071982549674"/>
    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
  </inertial>
  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
</link>

<link name="${prefix}tower_1">
  <inertial>
    <origin xyz="0.010000022826068933 0.009999792166619115 0.15999970226778837" rpy="0 0 0"/>
    <mass value="0.4359046662837625"/>
    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
  </inertial>
  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
</link>

<link name="${prefix}back_1">
  <inertial>
    <origin xyz="-0.2932579855783596 -0.44833419350146253 0.07234785241212485" rpy="0 0 0"/>
    <mass value="0.2451971061160035"/>
    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
  </inertial>
  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
</link>

<joint name="${prefix}Rigid_12" type="fixed">
  <origin xyz="0.237652 -0.018335 0.403258" rpy="0 0 0"/>
  <parent link="${prefix}tower_1"/>
  <child link="${prefix}yaw_bracket_1"/>
</joint>

<joint name="${prefix}Rigid_17" type="fixed">
  <origin xyz="-0.250902 0.038585 -0.085258" rpy="0 0 0"/>
  <parent link="${prefix}yaw_bracket_1"/>
  <child link="${prefix}yaw_servo_1"/>
</joint>

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
<joint name="${prefix}pan_joint" type="revolute">
  <origin xyz="-0.029 -0.01025 0.0032" rpy="0 0 0"/>
  <parent link="${prefix}yaw_servo_1"/>
  <child link="${prefix}yaw_mount_1"/>
  <axis xyz="0.0 0.0 1.0"/>
  <limit lower="-1.570796" upper="1.570796" effort="5" velocity="3.0"/>
  <dynamics damping="0.05" friction="0.05"/>
</joint>

<joint name="${prefix}Rigid_19" type="fixed">
  <origin xyz="-0.01615 0.01025 0.01325" rpy="0 0 0"/>
  <parent link="${prefix}yaw_mount_1"/>
  <child link="${prefix}pitch_servo_1"/>
</joint>

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
<joint name="${prefix}tilt_joint" type="revolute">
  <origin xyz="0.03405 -0.01025 0.029" rpy="0 0 0"/>
  <parent link="${prefix}pitch_servo_1"/>
  <child link="${prefix}pitch_link__1"/>
  <axis xyz="1.0 0.0 0.0"/>
  <limit lower="-1.570796" upper="1.570796" effort="5" velocity="3.0"/>
  <dynamics damping="0.05" friction="0.05"/>
</joint>

<joint name="${prefix}Rigid_21" type="fixed">
  <origin xyz="0.0043 -0.0105 0.032396" rpy="0 0 0"/>
  <parent link="${prefix}pitch_link__1"/>
  <child link="${prefix}realsense_1"/>
</joint>

<joint name="${prefix}Rigid_28" type="fixed">
  <origin xyz="-0.621592 -0.475076 0.0" rpy="0 0 0"/>
  <parent link="${prefix}back_1"/>
  <child link="${prefix}mod_101_adapter_1"/>
</joint>

<joint name="${prefix}Rigid_30" type="fixed">
  <origin xyz="0.878367 -0.199837 -0.028503" rpy="0 0 0"/>
  <parent link="${prefix}base_link"/>
  <child link="${prefix}tower_1"/>
</joint>

<joint name="${prefix}Rigid_31" type="fixed">
  <origin xyz="0.941625 0.158497 -0.090851" rpy="0 0 0"/>
  <parent link="${prefix}base_link"/>
  <child link="${prefix}back_1"/>
</joint>

</xacro:macro>

</robot>

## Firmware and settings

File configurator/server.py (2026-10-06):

#!/usr/bin/env python3
"""mod101 configurator backend.

Serves configurator/ as static files. Endpoints:
  GET  /load              - read the arm variant and build args (shoulder/elbow rail
                            length + shoulder/elbow mount) from
                            src/mod101_description/urdf/mod101_config.xacro
  POST /save              - write those build settings back in-place (fast; does
                            NOT rebuild the collision matrices)
  GET  /payload           - existing 6DOF reference + CAD-derived variant/tool corrections
  GET  /masses            - return src/mod101_description/link_masses.json
                            (Part C output) so the page uses real printed masses
  GET  /tool, POST /tool  - active end-effector package + discovery
  GET  /collisions        - self-collision matrix status: running, last result,
                            and `stale` (do the generated matrices still match
                            the args on disk?). mod101 only; consumers run their
                            own — see DOWNSTREAM_NOTE
  POST /collisions/regen  - rebuild the matrices. Slow (minutes at
                            REGEN_TRIALS); its own button in the UI
  GET  /urdf              - run `xacro` and return the expanded URDF, with
                            mesh URIs rewritten to /pkg/<pkg>/meshes/<file>
  GET  /pkg/<pkg>/meshes/<file> - serve binary mesh files from any package
  GET  /calibration       - read back the generated calibration artifacts
  POST /calibration       - write calibration.yaml (ROS) + lerobot_calibration
                            .json from calibrate.html's sweep results

Servo bus (see motors.py — talks to the Feetech chain over USB-TTL directly):
  GET  /bus               - connection status + known servo IDs
  GET  /bus/ports         - candidate serial devices
  POST /bus/connect       - {port} open the bus and scan it
  POST /bus/disconnect    - disarm + close
  POST /bus/scan          - re-ping the bus
  POST /bus/disarm        - torque off everything (also the unload beacon)
  GET  /servo/<id>        - one servo's telemetry
  GET  /servo/<id>/correction - its stored zero offset (EEPROM reg 31/32)
  POST /servo/<id>/torque - {on}
  POST /servo/<id>/move   - {pos, speed?, accel?}
  POST /servo/<id>/profile- {speed, accel}
  POST /servo/<id>/zero   - {target} define the current position as `target`
  POST /servo/<id>/id     - {to} reassign servo ID

Requires PyYAML, numpy and trimesh (payload geometry). Run from project root:
    python3 configurator/server.py
"""

import atexit
import datetime
import http.server
import json
import threading
import pathlib
import os
import re
import shutil
import socketserver
import subprocess
import sys
import tempfile
import yaml
from pathlib import Path

# Run as `python3 configurator/server.py` this is already sys.path[0], but be
# explicit so importing server.py as a module (tests) resolves motors too.
sys.path.insert(0, str(Path(__file__).resolve().parent))
import tool_options
from motors import BUS, BusError  # noqa: E402

PORT = 8001
HERE = Path(__file__).resolve().parent
ROOT = HERE.parent
SRC  = ROOT / 'src'
DESC = SRC / 'mod101_description'
# What we render for the live preview...
XACRO = DESC / 'urdf' / 'mod101.xacro'
# ...and what we actually edit. The four build args + tool live in their own
# file so every consumer of the mod101_arm macro (the standalone arm, base101,
# anything else) includes the same source of truth instead of only mod101.xacro.
CONFIG = DESC / 'urdf' / 'mod101_config.xacro'

MASSES = DESC / 'link_masses.json'

# Calibration artifacts written by configurator/calibrate.html. Both are
# generated files — the wizard is the source of truth, not hand edits.
CAL_DIR = SRC / 'mod101_control' / 'config'
CAL_YAML = CAL_DIR / 'calibration.yaml'
CAL_LEROBOT = CAL_DIR / 'lerobot_calibration.json'

# The hardware bringup's servo config. `SERVOS_YAML` is HAND-AUTHORED — bus
# port, rates, which groups exist, speeds, accelerations, safety flags — and
# this server never writes it. `SERVOS_GENERATED` is the half the configurator
# knows: which motor ID is which joint and which way it turns. The launch
# merges the second over the first.
#
# Two files rather than one because a generator that rewrites a hand-authored
# file eats the comments explaining why the numbers are what they are, and
# those comments are the only record of, say, why the shoulder runs at half
# speed. Keeping the machine's half separate means neither can clobber the
# other.
HW_DIR = SRC / 'hardware' / 'mod101_hw_bringup' / 'config'
SERVOS_YAML = HW_DIR / 'servos.yaml'
SERVOS_GENERATED = HW_DIR / 'servos.generated.yaml'

# The two rail-length build args: <xacro:arg name="shoulder_ext_length" default="0.130"/>
LEN_ARG_RE = re.compile(
    r'(<xacro:arg\s+name="(?P<name>shoulder_ext_length|elbow_ext_length)"\s+default=")'
    r'(?P<val>[^"]+)'
    r'(")'
)

# The two mount build args: <xacro:arg name="shoulder_mount" default="small"/>
MOUNT_ARG_RE = re.compile(
    r'(<xacro:arg\s+name="(?P<name>shoulder_mount|elbow_mount)"\s+default=")'
    r'(?P<val>[^"]+)'
    r'(")'
)

# `<xacro:arg name="tool" default="<value>"/>` — selects the end-effector pkg.
TOOL_ARG_RE = re.compile(
    r'(<xacro:arg\s+name="tool"\s+default=")'
    r'(?P<val>[^"]+)'
    r'(")'
)


def list_tools() -> list[str]:
    """Discover available tool packages on disk (sibling mod101_tool_* dirs)."""
    out = []
    for child in sorted((ROOT / 'src').iterdir()):
        if child.is_dir() and child.name.startswith('mod101_tool_'):
            out.append(child.name[len('mod101_tool_'):])
    return out


def read_tool() -> str:
    m = TOOL_ARG_RE.search(CONFIG.read_text())
    if not m:
        raise RuntimeError(f'Could not find <xacro:arg name="tool"> in {CONFIG}.')
    return m['val']


def write_tool(name: str) -> None:
    available = list_tools()
    if name not in available:
        raise ValueError(f'Unknown tool {name!r}. Available: {available}')

    def sub(m: re.Match) -> str:
        return f'{m.group(1)}{name}{m.group(3)}'

    new_text, n = TOOL_ARG_RE.subn(sub, CONFIG.read_text())
    if n != 1:
        raise RuntimeError(f'Expected 1 replacement for tool arg, did {n}')
    CONFIG.write_text(new_text)


MOUNTS = ('small', 'big')


def read_props() -> dict:
    """Return arm variant, two lengths (m), and two mounts."""
    text = CONFIG.read_text()
    lens: dict[str, float] = {}
    for m in LEN_ARG_RE.finditer(text):
        lens[m['name']] = float(m['val'])
    mounts: dict[str, str] = {}
    for m in MOUNT_ARG_RE.finditer(text):
        mounts[m['name']] = m['val']
    if {'shoulder_ext_length', 'elbow_ext_length'} - lens.keys():
        raise RuntimeError(f'Both extrusion length args not found in {CONFIG}.')
    if {'shoulder_mount', 'elbow_mount'} - mounts.keys():
        raise RuntimeError(f'Both mount args not found in {CONFIG}.')
    return {
        'tool_options': tool_options.read_values(text, tool_options.specs(SRC)),
        'wrist_camera': re.search(r'<xacro:arg\s+name="wrist_camera"\s+default="(true|false)"', text).group(1) == 'true',
        'arm_dof': int(re.search(r'<xacro:arg\s+name="arm_dof"\s+default="([67])"', text).group(1)),
        'shoulder': lens['shoulder_ext_length'],
        'elbow': lens['elbow_ext_length'],
        'shoulder_mount': mounts['shoulder_mount'],
        'elbow_mount': mounts['elbow_mount'],
    }


def write_props(shoulder_m: float, elbow_m: float,
                shoulder_mount: str, elbow_mount: str, arm_dof: int = 6, wrist_camera: bool | None = None, extra_options: dict | None = None) -> None:
    options = tool_options.validate(extra_options or {}, tool_options.specs(SRC))
    if wrist_camera is not None and not isinstance(wrist_camera, bool):
        raise ValueError("wrist_camera must be a boolean")
    if arm_dof not in (6, 7):
        raise ValueError("arm_dof must be 6 or 7")
    for label, v in (('shoulder', shoulder_m), ('elbow', elbow_m)):
        if not (0.05 <= v <= 0.40):
            raise ValueError(f'{label} length {v} m outside [0.05, 0.40]')
    for label, mnt in (('shoulder', shoulder_mount), ('elbow', elbow_mount)):
        if mnt not in MOUNTS:
            raise ValueError(f'{label} mount {mnt!r} not in {MOUNTS}')

    lengths = {'shoulder_ext_length': shoulder_m, 'elbow_ext_length': elbow_m}
    mounts = {'shoulder_mount': shoulder_mount, 'elbow_mount': elbow_mount}

    text = CONFIG.read_text()
    text, n = LEN_ARG_RE.subn(
        lambda m: f'{m.group(1)}{lengths[m["name"]]:.4f}{m.group(4)}', text)
    if n != 2:
        raise RuntimeError(f'Expected 2 length replacements, did {n}')
    text, n = MOUNT_ARG_RE.subn(
        lambda m: f'{m.group(1)}{mounts[m["name"]]}{m.group(4)}', text)
    if n != 2:
        raise RuntimeError(f'Expected 2 mount replacements, did {n}')
    text = re.sub(r'(<xacro:arg\s+name="arm_dof"\s+default=")[^"]+("/>)', lambda m: m[1] + str(arm_dof) + m[2], text)
    if wrist_camera is not None:
        text, n = re.subn(r'(<xacro:arg\s+name="wrist_camera"\s+default=")[^"]+("/>)',
                         lambda m: m[1] + str(wrist_camera).lower() + m[2], text)
        if n != 1:
            raise RuntimeError('Expected exactly one wrist_camera argument')
    text = tool_options.write_values(text, options, tool_options.specs(SRC))
    CONFIG.write_text(text)



# ---------------------------------------------------------------------------
# Self-collision matrix
# ---------------------------------------------------------------------------
# Changing a rail length or a mount moves the arm's reach, which changes which
# link pairs can never touch. mod101's own matrix derives from the build params,
# so a Save invalidates it — but does NOT rebuild it. Writing the xacro is
# instant and rebuilding takes minutes, so they are separate actions with
# separate buttons, and `stale` tells the UI when the second one is owed.
#
# THIS REGENERATES mod101 AND NOTHING ELSE. It used to reach into a base101
# workspace as well, which inverted the dependency: the arm knew about a robot
# that embeds it. A consumer can live anywhere, be absent, be unbuilt, or not be
# base101 at all — so each consumer owns its own regeneration and the
# configurator only tells you to run it. See DOWNSTREAM_NOTE.
REGEN_TIMEOUT = 900

# Surfaced in /save, /tool and /collisions responses so the page can tell you
# what still needs doing. A pointer, deliberately not an integration.
DOWNSTREAM_NOTE = (
    'Robots that embed the mod101_arm macro keep their own self-collision '
    'matrices and are NOT regenerated from here. Re-run that workspace\'s sync '
    'script after this change. For base101 that is '
    '`base101_arm_moveit_config/scripts/sync_arm_change.sh`.'
)

_regen_lock = threading.Lock()
_regen_state = {'running': False, 'last': None}


def _regen_targets():
    """(label, script, workspace-setup) for each matrix generator that exists."""
    return [('mod101', ROOT / 'tools' / 'gen_collision_matrix.py', ROOT)]


# The configurator asks for a thorough run, not the generator's quick default.
# See MATRIX_TRIALS in gen_collision_matrix.py's docstring for the convergence
# data: at 10,000 the matrix wrongly disables pairs that really can collide,
# which is the dangerous direction. A Save is rare and now has its own button,
# so it can afford to be slow and right.
REGEN_TRIALS = 1_000_000


def _regen_worker(trials=REGEN_TRIALS):
    results = {}
    for label, script, ws in _regen_targets():
        setup = ws / 'install' / 'setup.bash'
        if not setup.is_file():
            results[label] = 'skipped: workspace not built'
            print(f'[collisions] {label}: {results[label]}')
            continue
        # A login shell so the generator sees ROS and this workspace's overlay.
        cmd = (f'source /opt/ros/$ROS_DISTRO/setup.bash && '
               f'source {setup} && python3 {script} --trials {trials}')
        try:
            proc = subprocess.run(['bash', '-lc', cmd], capture_output=True,
                                  text=True, timeout=REGEN_TIMEOUT)
            results[label] = 'ok' if proc.returncode == 0 else \
                f'failed ({proc.returncode})'
            if proc.returncode != 0:
                print(f'[collisions] {label} failed:\n{proc.stderr[-2000:]}')
            else:
                print(f'[collisions] {label}: regenerated')
        except subprocess.TimeoutExpired:
            results[label] = 'timed out'
            print(f'[collisions] {label}: timed out after {REGEN_TIMEOUT}s')
    with _regen_lock:
        _regen_state['running'] = False
        _regen_state['last'] = results


MATRIX_DIR = SRC / 'mod101_moveit_config' / 'config' / 'collisions'
STAMP_RE = re.compile(
    r'shoulder_ext_length=(?P<sl>[\d.]+)\s+elbow_ext_length=(?P<el>[\d.]+)\s+'
    r'shoulder_mount=(?P<sm>\w+)\s+elbow_mount=(?P<em>\w+)')


def matrices_stale() -> bool | None:
    """Do the generated matrices still match the args on disk?

    Read from the generated files' own build stamp rather than remembering
    whether a Save happened, so it survives a server restart and is still right
    if someone edits the xacro by hand. None = can't tell (no matrices yet).
    """
    try:
        cur = read_props()
    except Exception:
        return None
    for f in sorted(MATRIX_DIR.glob('*.srdf.xacro')):
        m = STAMP_RE.search(f.read_text())
        if not m:
            return None
        if (abs(float(m['sl']) - cur['shoulder']) > 1e-6
                or abs(float(m['el']) - cur['elbow']) > 1e-6
                or m['sm'] != cur['shoulder_mount']
                or m['em'] != cur['elbow_mount']):
            return True
    return False


def regen_collisions_async(trials: int = REGEN_TRIALS):
    """Kick off regeneration of mod101's own matrices unless one is in flight.

    Consumers are never touched — `downstream` is what you have to run yourself.
    """
    with _regen_lock:
        if _regen_state['running']:
            return {'running': True, 'note': 'already regenerating',
                    'downstream': DOWNSTREAM_NOTE, 'trials': trials}
        _regen_state['running'] = True
    threading.Thread(target=_regen_worker, args=(trials,), daemon=True).start()
    return {'running': True,
            'targets': [label for label, _, _ in _regen_targets()],
            'downstream': DOWNSTREAM_NOTE, 'trials': trials}


def regen_status():
    with _regen_lock:
        state = dict(_regen_state)
    return {**state, 'downstream': DOWNSTREAM_NOTE,
            'stale': matrices_stale(), 'trials': REGEN_TRIALS}


def read_masses() -> dict:
    """Part C output. {'masses': {...}} or {'masses': None} if not generated."""
    if not MASSES.is_file():
        return {'masses': None}
    return {'masses': json.loads(MASSES.read_text())}


def read_calibration() -> dict:
    """Return whatever calibration artifacts exist on disk (None when absent)."""
    return {
        'yaml': CAL_YAML.read_text() if CAL_YAML.is_file() else None,
        'lerobot': (json.loads(CAL_LEROBOT.read_text())
                    if CAL_LEROBOT.is_file() else None),
        'servos': (SERVOS_GENERATED.read_text()
                   if SERVOS_GENERATED.is_file() else None),
    }


def _authored_groups() -> dict:
    """group name -> list of joint names, from the hand-authored servos.yaml.

    GROUP MEMBERSHIP IS READ, NOT INFERRED. The obvious shortcut is to sort
    joints by name here — anything starting `hn_` is the head, `6` is the tool
    — which is exactly the guessing that used to live in the ros2_control
    bridge and put the pan/tilt joints on the arm's topic. The authored file
    already states the answer; this reads it.
    """
    if not SERVOS_YAML.is_file():
        raise ValueError(
            f'{SERVOS_YAML.relative_to(ROOT)} not found — it defines which '
            f'groups exist and which joints belong to them, and this server '
            f'only fills in the per-motor half')
    servos = SERVOS_YAML.with_name('servos.7dof.yaml') if read_props()['arm_dof'] == 7 else SERVOS_YAML
    doc = yaml.safe_load(servos.read_text()) or {}
    params = (doc.get('servo_manager_node') or {}).get('ros__parameters') or {}
    groups = {}
    for name in params.get('group_names') or []:
        block = params.get(name)
        if isinstance(block, dict):
            groups[name] = [str(j) for j in (block.get('joint_names') or [])]
    if not groups:
        raise ValueError(f'{SERVOS_YAML.name} declares no usable groups')
    return groups


def render_servo_map(entries: list) -> tuple[str, list]:
    """The configurator's servo map as servo-manager parameters.

    `entries` is one dict per servo: {id, joint, sign}. Returns the YAML text
    and a list of human-readable warnings.

    The order of joints inside a group is NOT this function's choice — it comes
    from the authored file, because that same order is the layout of the
    Float64MultiArray the ros2_control bridge publishes on that group's topic.
    Sorting by motor ID here would silently reorder the wire format.
    """
    groups = _authored_groups()
    by_joint = {}
    for e in entries:
        joint = str(e.get('joint') or '').strip()
        if joint:
            by_joint[joint] = e

    warnings, out, state_index = [], {}, 0
    for gname, joints in groups.items():
        ids, names, dirs, cmd_idx, st_idx = [], [], [], [], []
        for joint in joints:
            e = by_joint.pop(joint, None)
            if e is None:
                warnings.append(
                    f'group "{gname}": no servo mapped to {joint} — left as authored')
                continue
            ids.append(int(e['id']))
            names.append(joint)
            dirs.append(1 if int(e.get('sign', 1)) >= 0 else -1)
            cmd_idx.append(len(names) - 1)     # index within this group's array
            st_idx.append(state_index)         # slot in the shared JointState
            state_index += 1
        if ids:
            out[gname] = dict(motor_ids=ids, joint_names=names, direction=dirs,
                              command_indices=cmd_idx, state_indices=st_idx)
    for joint in by_joint:
        warnings.append(f'{joint} is mapped to a servo but belongs to no group '
                        f'in servos.yaml — it will not be driven')

    lines = [
        '# GENERATED by configurator/calibrate.html — do not edit.',
        '#',
        '# The per-motor half of the servo manager config: which motor ID is',
        '# which joint, which way it turns, and where it sits in the arrays.',
        '# Everything else — port, rates, speeds, accelerations, which groups',
        '# exist — is hand-authored in servos.yaml, which this never touches.',
        '# bringup.launch.py loads servos.yaml and merges this over it.',
        '#',
        '# Joint order within a group comes from servos.yaml and IS the layout',
        '# of the command array on that group\'s topic. It is not sorted here.',
        '#',
        f'# generated: {datetime.datetime.now(datetime.timezone.utc).isoformat()}',
        'servo_manager_node:',
        '  ros__parameters:',
    ]
    for gname, g in out.items():
        lines.append(f'    {gname}:')
        lines.append(f'      motor_ids: {g["motor_ids"]}')
        lines.append('      joint_names: [' +
                     ', '.join(f'"{n}"' for n in g['joint_names']) + ']')
        lines.append(f'      direction: {g["direction"]}')
        lines.append(f'      command_indices: {g["command_indices"]}')
        lines.append(f'      state_indices: {g["state_indices"]}')
    return '\n'.join(lines) + '\n', warnings


def write_calibration(yaml_text: str, lerobot: dict,
                      servos: list | None = None) -> tuple[list, list]:
    """Persist the wizard's output. `yaml_text` is rendered client-side so the
    page's preview and the file on disk can't drift; we only sanity-check it."""
    if not isinstance(yaml_text, str) or 'mod101_calibration:' not in yaml_text:
        raise ValueError('yaml payload missing the mod101_calibration root key')
    if not isinstance(lerobot, dict) or not lerobot:
        raise ValueError('lerobot payload must be a non-empty object')
    for name, entry in lerobot.items():
        missing = {'id', 'drive_mode', 'homing_offset',
                   'range_min', 'range_max'} - set(entry)
        if missing:
            raise ValueError(f'{name}: missing {sorted(missing)}')

    CAL_DIR.mkdir(parents=True, exist_ok=True)
    CAL_YAML.write_text(yaml_text)
    CAL_LEROBOT.write_text(json.dumps(lerobot, indent=2) + '\n')
    written = [CAL_YAML, CAL_LEROBOT]

    warnings = []
    if servos:
        text, warnings = render_servo_map(servos)
        HW_DIR.mkdir(parents=True, exist_ok=True)
        SERVOS_GENERATED.write_text(text)
        written.append(SERVOS_GENERATED)
    return [str(p.relative_to(ROOT)) for p in written], warnings


_SRC_OVERLAY: str | None = None
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

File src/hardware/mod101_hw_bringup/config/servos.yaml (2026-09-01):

# The mod101 harness's Feetech bus, as st3215_manager sees it.
#
# Eight STS3215 servos on ONE RS-485 chain: the five arm joints, the jaw, and
# the two pan/tilt head joints. One bus, one node — st3215_manager opens a
# single `port`, so a second chain means a second node with its own config and
# a different `joint_states_topic`, not more groups in here.
#
# THREE GROUPS, MATCHING THE THREE <ros2_control> GROUPS IN THE URDF. The group
# names, the joint names and the ORDER of the joints inside each group have to
# agree with the `group` params in mod101_harness/urdf/mod101_harness_arm.xacro
# and mod101_tool_jaws/urdf/tool.ros2control, because that order is the layout
# of the Float64MultiArray the bridge publishes on each group's topic. Reorder
# one side and the wrong servo moves.
#
# MOTOR IDs ARE AN ASSUMPTION UNTIL YOU CHECK THEM. 1-6 are the SO-101 factory
# order (mod101_description/urdf/mod101_macro.xacro), and 7-8 for the head are
# a convention this file is choosing. Scan the bus with the configurator
# (`python3 configurator/server.py` -> Calibrate -> Hardware -> Rescan) and fix
# them here if they differ; the IDs live in servo EEPROM, not in this file.
#
# CALIBRATION IS NOT IN THIS FILE. home_ticks / min_ticks / max_ticks are
# injected at launch from mod101_control/config/calibration.yaml, which the
# configurator writes. Overriding them here is possible but means the arm's
# zero is defined in two places; see bringup.launch.py.
servo_manager_node:
  ros__parameters:
    # A udev name, not /dev/ttyACMn, because ACM numbering is assignment order
    # and moves whenever anything re-enumerates — this bench has already gone
    # ACM1 -> ACM0 once. docker/udev/99-mod101-servo.rules pins the adapter by
    # its serial number so this name always lands on the same cable. Override
    # with serial_port:=... for a second bench.
    #
    # INSIDE THE CONTAINER THIS IS ALWAYS THE NAME, whatever the host calls the
    # device: hardware.compose.yaml maps ${MOD101_BUS} onto /dev/mod101-servo,
    # so a host with no udev rules only has to set that one variable.
    port: "/dev/mod101-servo"
    baud: 1000000
    ticks_per_rev: 4096

    # 50 Hz of joint states for a 50 Hz controller_manager. This used to be
    # "already most of the budget" and no longer is: read_motor_state now
    # fetches position AND speed in ONE 4-byte read (registers 56-59 are
    # contiguous) instead of two, so eight motors cost 2.1 ms per cycle rather
    # than 4.1 — about a tenth of the bus. Kept at 50 rather than cut, because
    # the reason to cut it has been removed.
    telemetry_rate: 50.0
    joint_states_topic: "/motor_manager/joint_states"
    total_joints: 8

    brake_method: "torque_disable"
    velocity_ramp_time: 0.1
    brake_acceleration: 100

    # Per-motor current/voltage/load/temperature on /motor_telemetry/<joint>/*.
    # ON, but at 1 Hz rather than the 5 it was first set to.
    #
    # AVERAGE DUTY IS NOT THE PROBLEM HERE, BURST LENGTH IS. This is four
    # separate reads per motor -- current, voltage, load, temperature -- so
    # eight motors is 32 round trips, 8.3 ms, taken back to back on a
    # single-threaded executor. Nothing else on that thread runs during it:
    # not a joint state, not an incoming position command. At 5 Hz that stall
    # landed five times a second and was long enough to swallow a whole
    # control cycle. At 1 Hz it lands once, and load and temperature are slow
    # signals that lose nothing by being sampled that way -- they are here to
    # warn before a servo stalls or cooks, not to be controlled on.
    motor_telemetry_enable: true
    motor_telemetry_rate: 1.0

    # Never true on an assembled arm. The test sequence drives each motor a
    # little way with no knowledge of its travel limits.
    test_on_startup: false

    # Refuse to start unless all eight answer. The usual reason they do not is
    # motor power: the logic side is fed from USB, so the port opens and the
    # chain stays silent, which looks like a working driver with a dead robot.
    require_motors: true

    group_names: ["arm", "tool", "head"]
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

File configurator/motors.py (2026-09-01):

#!/usr/bin/env python3
"""Serial-bus motor layer for the configurator's calibration page.

Talks to the Feetech ST/STS chain directly over a USB-TTL adapter using the
`st3215` library (pip install st3215) — no intermediate firmware. The browser
never touches the serial port; it drives this over HTTP from server.py.

The one class here, `MotorBus`, is a thin normalizing wrapper. `st3215` is
inconsistent about return values and this is where that gets flattened:

  * `ReadSpeed`   returns a 3-tuple `(speed, comm, error)` while every other
                  `Read*` returns a scalar or None.
  * `StartServo`  returns `(comm, error)` while `StopServo` returns True/None.
  * `ChangeId`    returns None on SUCCESS and an error string on failure —
                  but "success" only means the bytes reached the UART, since
                  its EPROM ops are all TxOnly. See change_id(), which pings
                  the new ID to find out what actually happened.
  * `ReadVoltage` returns volts; `ReadLoad` returns a ±1023 duty cycle.

Bus access is serialized under a lock. `socketserver.TCPServer` handles one
request at a time today, but the telemetry poller is chatty enough that this
should not silently depend on that.
"""

import atexit
import fcntl
import glob
import os
import threading
import time

DEFAULT_SCAN_HI = 99      # servo IDs above this aren't scanned (ListServos
                          # pings 0..253, which takes seconds on a real bus)
# EEPROM registers and the comm status code, from st3215/values.py. Mirrored
# here rather than imported because st3215 is imported lazily, in connect().
REG_ID = 5
REG_OFS_L = 31            # position-correction offset, EEPROM, 2 bytes
REG_TORQUE_ENABLE = 40
REG_LOCK = 55
REG_MODE = 33             # 0 position, 1 constant speed, 2 PWM, 3 step
COMM_OK = 0
TICKS = 4096
MAX_OFS = 2047            # the offset register is 11 bits plus a sign bit
LOAD_FULL_SCALE = 1023.0  # ReadLoad duty-cycle range


class BusError(RuntimeError):
    """Any failure that should surface to the browser as a 4xx."""


def port_holders(device: str) -> list[tuple[int, str]]:
    """Every other process holding `device` open, as (pid, cmdline).

    Linux permits several processes to open the same tty, and then splits the
    incoming bytes between them at random — so a stray `miniterm`, a second
    server, or a ROS driver makes every servo reply come back truncated and the
    bus looks dead rather than busy. Nothing in the serial stack reports that,
    so check for it explicitly. Same method as fuser(1): walk /proc/*/fd.
    """
    target = os.path.realpath(device)
    me = os.getpid()
    out: list[tuple[int, str]] = []
    for fddir in glob.glob('/proc/[0-9]*/fd'):
        try:
            pid = int(fddir.split('/')[2])
        except ValueError:
            continue
        if pid == me:
            continue
        try:
            entries = os.listdir(fddir)
        except OSError:
            continue                      # not ours / already gone
        for fd in entries:
            try:
                if os.path.realpath(os.path.join(fddir, fd)) != target:
                    continue
                with open(f'/proc/{pid}/cmdline', 'rb') as fh:
                    cmd = fh.read().replace(b'\0', b' ').decode(
                        'utf-8', 'replace').strip()
                out.append((pid, cmd or f'pid {pid}'))
                break
            except OSError:
                break
    return out


class MotorBus:
    """Owns the serial port and every servo transaction on it."""

    def __init__(self):
        self._st = None
        self._port = None
        self._lock = threading.RLock()
        self._seen: list[int] = []
        atexit.register(self.disarm_all)

    # ---- lifecycle -----------------------------------------------------

    @property
    def connected(self) -> bool:
        return self._st is not None

    def _require(self):
        if self._st is None:
            raise BusError('not connected to a servo bus')
        return self._st

    def connect(self, port: str) -> dict:
        from st3215 import ST3215
        with self._lock:
            if self._st is not None:
                self.disconnect()

            holders = port_holders(port)
            if holders:
                who = '; '.join(f'pid {p} ({c[:70]})' for p, c in holders)
                raise BusError(
                    f'{port} is already open by {who}. Close it first — two '
                    'readers on one serial port split the servo replies '
                    'between them, so every reply arrives corrupt and the bus '
                    'looks empty.')

            try:
                self._st = ST3215(port)
            except Exception as e:
                # ST3215 raises bare ValueError('Could not open port: ...')
                raise BusError(f'could not open {port}: {e}') from e

            # Advisory lock, same mechanism as pyserial's exclusive=True (which
            # st3215 doesn't pass). Stops a *later* opener that also locks.
            try:
                fcntl.flock(self._st.portHandler.ser.fileno(),
                            fcntl.LOCK_EX | fcntl.LOCK_NB)
            except OSError:
                self._st = None
                raise BusError(f'{port} is locked by another process')

            self._port = port
            return self.scan()

    def disconnect(self) -> None:
        with self._lock:
            if self._st is None:
                return
            try:
                self.disarm_all()
            except Exception:
                pass
            try:
                self._st.portHandler.closePort()
            except Exception:
                pass
            self._st = None
            self._port = None
            self._seen = []

    def status(self) -> dict:
        return {
            'connected': self.connected,
            'port': self._port,
            'servos': list(self._seen),
        }

    # ---- discovery -----------------------------------------------------

    @staticmethod
    def list_ports() -> list[dict]:
        """Candidate serial devices, most likely first.
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

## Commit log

2026-05-12 changes to the readme, added virt camera, moved to humble
    [controllers.sim.yaml]
2026-05-12 jazzy again, don't judge
    [mod101.xacro]
2026-05-13 big refactor, added modular architecture and configurator
    [Parallel_gripper_assembly_v1_1.stl, controllers.sim.yaml, controllers.yaml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]
2026-05-13 added pincopen as tool
    [Gripper_Palm_Shell_w_motor_v1.stl, controllers.yaml, gripper_left_arm.stl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]
2026-05-13 configurator + tool convention: visual port from robocore-studio (Inter / Tomorrow, teal accent on black, ghost buttons), preview-on-top responsive layout with Configuration + Joint pose on the right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
    [Moving_Jaw_08d_v1_1.stl, Wrist_Roll_08c_v1_1.stl, arm_gripper_servo_1.stl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]
2026-06-02 updated with motor links
2026-06-16 Update servo links in README.md
2026-06-24 Part A: consolidate arm into one parametric URDF
    Retrofit the modular mod101_arm macro with the integration spec's four build
    args (shoulder_ext_length, elbow_ext_length, shoulder_mount, elbow_mount) so the
    configurator drives any member of the family directly.
    - Canonical joint vocabulary: joint_base / joint_shoulder / joint_elbow /
    joint_wrist_tilt / joint_wrist_roll; fixed joints -> fixed_<childlink>.
    No CAD auto-names remain (git grep -iE '(revolute|rigid) [0-9]' is clean).
    - Elbow axis canonicalized to 0 1 0 (resolves the two exports' sign
    disagreement by construction). Base axis kept pending hardware confirmation.
    - Per-joint mount selector (A3): big mount swaps servo body mass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
    [controllers.sim.yaml, mod101.hardware.xacro, mod101.xacro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]
2026-06-24 Part C: PLA-CF printed-mass estimator + link_masses.json
    tools/estimate_masses.py estimates printed-part mass from STL geometry with a
    dense-shell + sparse-infill model (PLA-CF, 15% infill, 1.6 mm shell), so the
    configurator/URDF use real masses instead of guesses.
    - trimesh volume/area; clamps shell to solid (min) so thin parts don't exceed
    solid mass; flags non-watertight meshes instead of emitting garbage volume.
    - --rho/--infill/--wall/--units, --printed-only name filter (excludes servo
    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
2026-06-24 Part B: configurator v2 — per-joint motors, payload, masses, cost
    Rewrite the configurator onto the v2 model and wire it to Part A's four args.
    - Per-joint motor dropdowns (STS3215/STS3250/ST3120, ST3120 peak 120 kg·cm) map
    1:1 to the URDF mount args; two length inputs -> *_ext_length.
    - Mount delta feeds the torque lever; static payload at the binding pitch joint,
    three duty regimes x two reaches, binding joint named, duty@full headline.
    - Real printed masses from link_masses.json (/masses) with lumped fallback +
    badge.
    - Display-only servo cost; S/M/L t-shirt presets; Reload-preview button.
    - server.py reads/writes all four args, serves /masses, and renders /urdf from a
    temp am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
    [server.py]
2026-08-06 lots of changes
    [Gripper_Palm_Shell_w_motor_v1.stl, arm_extrusion_1.stl, base_cover_1.stl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]
2026-08-06 big changes
    [controllers.sim.yaml, mod101.hardware.xacro, mod101.xacro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]
2026-08-06 Revise README for configurator and calibration updates
    Updated the README to reflect changes in configurations, calibration, and pricing details.
2026-08-17 moveit tweaks
    [Gripper_Palm_Shell_w_motor_v1.stl, Moving_Jaw_08d_v1_1.stl, Parallel_gripper_assembly_v1_1.stl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]
2026-08-24 small tweaks for integration with robocore-sdk and base101
    [mod101_config.xacro]
2026-08-28 added the harness
    [back_1.stl, base_link.stl, harness.gazebo.xacro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]
2026-08-28 changes to the configurator
    [pan_tilt_controllers.yaml]
2026-08-29 docker configuration, but it still sucks
    [harness.gazebo.xacro, harness_body.xacro, table.sdf]
2026-08-30 fixed motor ids in calibration and bug in harness
    [harness.gazebo.xacro, harness_body.xacro, table.sdf]
2026-08-31 hardware is on
    [calibration.yaml, controllers.yaml, hardware.compose.yaml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]
2026-09-01 motor backlash tweaks, lowered control loop frequency, good stuff
    [calibration.yaml, controllers.yaml, hardware.compose.yaml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]
2026-09-01 fixes, added static TF link to realsense, profile for hardware harness
    [hardware.compose.yaml]
2026-10-06 added 7DOF, camera eend effector and PGGripper
    [Gripper.stp, body.stl, camera.7dof.srdf.xacro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]
